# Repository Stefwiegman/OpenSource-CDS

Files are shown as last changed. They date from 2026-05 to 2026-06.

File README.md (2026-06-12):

# Confocal Displacement Sensing

> **Affordable confocal displacement measurement.**
> *Confocal Displacements Sensing voor betaalbare verplaatsingsmetingen*

<p align="center">
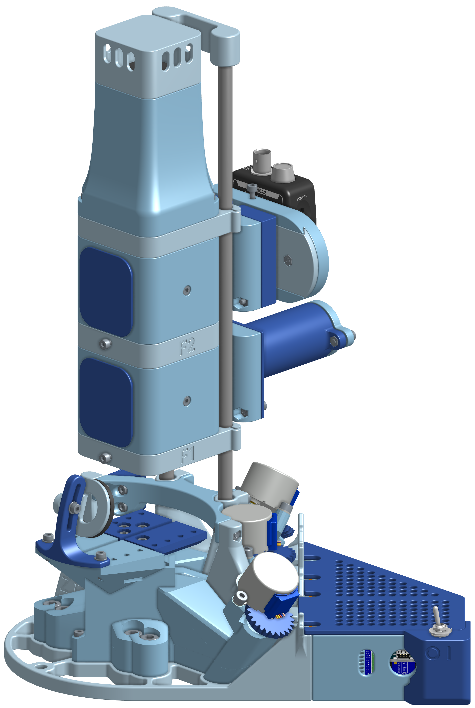
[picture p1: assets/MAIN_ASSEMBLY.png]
Confocal Displacement Sensor, CAD render of the assembled instrument
  
</p>

    

A Bachelor End Project (BEP) for the **Precision and Micro-Engineering** track at TU Delft (course `WBMT3BEP`, project code `PME-2026-A06`).
Submission: **June 12th 2026**.

**Team:** Dafne Gyselinck · Jayden Jhagru · Harmen Klerk · Ties van Lohuizen · Stef Wiegman

> 🧱 **Built on top of the [OpenFlexure Block Stage](https://openflexure.org/projects/blockstage/)** (CC BY-SA 4.0), used **unmodified** as our 3-axis flexure base. See [Built on top of](#-built-on-top-of) for what this means for builders, and for attribution.

---

## 🔗 Project Hub

Everything we made for this project lives behind one of these links.

| Deliverable | Link | What's inside |
|---|---|---|
| 📄 Research paper | [`docs/OpenSource_CDS_Paper.pdf`](docs/OpenSource_CDS_Paper.pdf) | "Frugal & Portable Monochromatic Confocal Displacement Sensing using the OpenFlexure framework": theory and confocal intensity model (Section II), grid-search lens selection, measured sensitivity vs. range, AFM-cantilever alignment, frequency-domain demonstration, discussion (PDF, download to view) |
| 🎥 Assembly video | [YouTube](https://youtu.be/qtCvRlFayCg) | Step-by-step build from printed parts and electronics to a working instrument |
| 📐 CAD files | [`cad/`](cad/) | 51 STEP files (`cad/step/`) for the confocal extension, plus 6 STL of the OpenFlexure stage (`cad/stl/`), grouped by category (BASE / BLOCKS / CALIBRATION / STAGE) |
| 🧩 Assembly viewer | [Onshape](https://cad.onshape.com/documents/87fafcc64806dd978cd8e8a6/w/b53780b5a9e32836df5ce22e/e/844e572a161a9db474edfe58) | Interactive 3D model of the full assembly: rotate and inspect in the browser, or export STEP / STL yourself |
| 🔧 Circuit diagram | [`docs/circuit-diagram.pdf`](docs/circuit-diagram.pdf) | Arduino pin-out, ULN2003 IN2/IN3-swap, power, Moku and camera connections (PDF, download to view) |
| 🛒 Parts list (BOM) | [`docs/OpenSource_CDS_BOM.xlsx`](docs/OpenSource_CDS_BOM.xlsx) | Electronics, optics, mechanical hardware, quantities, suppliers, prices (Excel, download to view) |
| 🖨️ 3D-print guide | [`docs/OpenSource_CDS_Printing_Guide.pdf`](docs/OpenSource_CDS_Printing_Guide.pdf) | Printer settings, per-part list with print times, filament estimates, tolerances |
| 📖 Use guide | [`docs/OpenSource_CDS_User_Guide.pdf`](docs/OpenSource_CDS_User_Guide.pdf) | Optical alignment (tower, LED, mirror, detector), laser calibration, powering on, homing the stage, finding I0 and the calibration sweep (PDF, download to view) |
| 🧱 Block stage origin | [openflexure.org/projects/blockstage](https://openflexure.org/projects/blockstage/) | Upstream open-hardware base, required reading before fabrication |
| 💻 Source code | this repository | PySide6 desktop UI, Arduino firmware, burst pipeline, confocal physics model |

---

## What is this?

A complete, low-cost **confocal displacement measurement instrument**, built from four parts:

- An **unmodified [OpenFlexure Block Stage](https://openflexure.org/projects/blockstage/)** as the 3-axis flexure base
- Our custom **confocal optical column** (two lenses, pinhole aperture, photodetector) that bolts onto the block stage
- Our **stepper actuators, electronics, and illumination** that also mount to the unmodified stage
- A desktop application that ties it all together for live alignment, calibration, and manual point measurements

The instrument **measures sub-micron axial displacement** (vertical position changes smaller than 1 µm) at one point on a sample. Repositioning the probe across a grid builds a spatial map: at each stand-still point the photodetector records a high-speed voltage burst (a few milliseconds at ≥1 MSa/s), and offline FFT analysis turns each burst into a vibration spectrum.

The goal is to deliver this capability at a small fraction of the cost of commercial confocal displacement sensors, making the technology accessible for academic and small-lab settings.

The motivating application is **vibration characterisation of MEMS-class structures**: each burst's spectrum becomes one point in a 3D dataset `(x, y, frequency) → amplitude`. In the paper this is demonstrated by aligning the laser on an AFM cantilever (≈450 µm × 50 µm) and recovering the known vibration frequencies of a stepper motor.

### Glossary

If terms below are new to you, this short table covers the rest of the README:

| Term | What it means here |
|---|---|
| **Confocal** | Optical setup where the illumination spot and detector pinhole share a common focus, gives the system its high axial (Z-axis) sensitivity |
| **Burst** | A short (few ms) high-rate sample of photodetector voltage taken at one stand-still position |
| **dz1** | Axial (Z) displacement of the sample from a reference plane, in mm |
| **I0** | Photodetector voltage at full reflection (the maximum of the calibration curve); the linear region sits around I0/2 |
| **Calibration line** | A straight line `I_m = a·dz1 + b` fitted to the steep middle of the confocal curve; inverting it (`dz1 = (V - b) / a`) turns measured voltage into displacement |
| **MEMS** | Micro-Electro-Mechanical Systems, micrometer-scale moving structures whose vibrations we characterise |
| **Moku:Go** | Liquid Instruments' multifunction lab instrument; it is the acquisition **back-end** that digitises the photodetector signal (Oscilloscope mode for live view, Datalogger mode for burst capture) |
| **Flexure stage** | A stage that moves via elastic flexion of monolithic features instead of sliding bearings, sub-micron repeatable, see OpenFlexure |

### Pick your starting point

- **Reading the paper?** Start with the [research paper](#-project-hub), then the [Hardware overview](#hardware-overview) for the optical setup.
- **Building a copy?** Read [Built on top of](#-built-on-top-of) first, then open the [3D-print guide](docs/OpenSource_CDS_Printing_Guide.pdf), [BOM](docs/OpenSource_CDS_BOM.xlsx), [circuit diagram](docs/circuit-diagram.pdf), and watch the [assembly video](https://www.youtube.com/watch?v=UzMbLptgHZc).
- **Running an existing instrument?** Jump to [Prerequisites](#prerequisites) and [Setup](#setup), then the [use guide](docs/OpenSource_CDS_User_Guide.pdf).
- **Hacking the software?** See [Repository layout](#repository-layout).

---

## Prerequisites

Before the software will do anything useful, make sure you have:

| Need | Why | How to verify |
|---|---|---|
| **Python ≥ 3.10** | UI + burst pipeline | `python --version` |
| **Git** | clone repo | `git --version` |
| **Arduino IDE** (or `arduino-cli`) | flash the Nano firmware once | open IDE, plug in Nano |
| **Moku:Go** + Liquid Instruments account | photodetector readout | reachable at `192.168.73.1` after connecting to its Access-Point Wi-Fi or Ethernet |
| **USB microscope camera** (UVC, ≥1080p) | live view of the sample on the Camera tab | the laptop's built-in webcam is never used; only an external camera is opened |
| **Assembled hardware** | otherwise the UI starts but cannot measure | see [3D-print guide](docs/OpenSource_CDS_Printing_Guide.pdf), [circuit diagram](docs/circuit-diagram.pdf), and the [assembly video](https://www.youtube.com/watch?v=UzMbLptgHZc) |

Estimated total build cost: **≈ €1600**, dominated by the Moku:Go (≈ €689) and the optics (lens and red filter, listed as approximate prices); see the [BOM](docs/OpenSource_CDS_BOM.xlsx) for the full breakdown.

---

## Setup

This chapter takes you from a fresh clone to all three TopBar status pills (`Motors / Moku / Camera`) turning green. For aligning and calibrating the instrument afterwards (optical alignment, laser calibration, finding I0, calibration sweep) see the [use guide](docs/OpenSource_CDS_User_Guide.pdf).

### 1. Clone and create a Python environment

**Windows (PowerShell):**

```powershell
git clone https://github.com/Stefwiegman/Bep-Project.git
cd Bep-Project
python -m venv .venv
.venv\Scripts\Activate.ps1
```

**Linux / macOS (bash/zsh):**

```bash
git clone https://github.com/Stefwiegman/Bep-Project.git
cd Bep-Project
python3 -m venv .venv
source .venv/bin/activate
```

### 2. Install dependencies

```bash
pip install -r requirements.txt
```

This pulls in the UI and pipeline stack: PySide6 (Qt UI), pyserial (Arduino link), the `moku` client, NumPy + matplotlib (math and plots), SymPy (confocal model), OpenCV + pygrabber (camera), pandas + openpyxl (Excel/CSV import in the Calibration graph tab) and PyYAML (calibration persistence).

> **Note:** `openpyxl` is the engine pandas uses to read `.xlsx` files. Without it the Calibration graph tab cannot open Excel measurement files, so it is pinned in `requirements.txt` even though pandas does not install it automatically.

### 3. Flash the Arduino firmware (one-time)

The stage motors and lamp are driven by an Arduino Nano. Flash it once with the Arduino IDE (or `arduino-cli`):

1. Open `arduino/firmware/firmware.ino`.
2. Install the required libraries via the Library Manager: **AccelStepper** and **Adafruit NeoPixel**.
3. Select board **Arduino Nano** and the correct COM-port, then **Upload**.

Note the port the Nano enumerates on, you pick it in the app later (the defaults assume `COM4`). Full wiring, including the ULN2003 IN2/IN3 swap, is in the [circuit diagram](docs/circuit-diagram.pdf).

### 4. Set up the Moku:Go (one-time)

The `moku` Python client deploys an instrument bitstream (Oscilloscope / Datalogger) to the Moku:Go's FPGA at runtime, and that bitstream must match the device's MokuOS version. Install the Liquid Instruments CLI, point the Python client at it, and cache the matching bitstreams once:

1. **Install the CLI.** Download and install `mokucli` from Liquid Instruments: [liquidinstruments.com/software/utilities](https://liquidinstruments.com/software/utilities/). On Windows it lands at `C:\Program Files\Liquid Instruments\Moku CLI\mokucli.exe`. **Keep the default install folder.** The Python client locates `mokucli` through the path you set in the next step, so moving the install folder breaks bitstream deployment.

2. **Tell the `moku` client where the CLI is.** Set the `MOKU_CLI_PATH` environment variable to the executable from the previous step. On Windows (run once, in a normal PowerShell or Command Prompt, then open a new terminal so the variable is picked up):
   ```powershell
   setx MOKU_CLI_PATH "C:\Program Files\Liquid Instruments\Moku CLI\mokucli.exe"
   ```
   If you installed `mokucli` somewhere else, point this at that path instead.

3. **Find the device security key.** Each Moku:Go has a unique key printed on the **sticker on the bottom of the device**. You need it the first time you claim or connect to the Moku:Go through your Liquid Instruments account.

4. **Read the MokuOS version.** Connect to the device first: join the Moku:Go's Wi-Fi Access Point or wire it over Ethernet, put your PC's network adapter on the same subnet (`192.168.73.x`), confirm it responds, then list it and note the firmware version reported:
   ```bash
   ping 192.168.73.1
   mokucli list
   ```

5. **Download the matching bitstreams.** This step pulls the bitstreams from Liquid Instruments' servers, so you must be **connected to the internet** (switch off the Moku:Go Access-Point Wi-Fi and back onto your normal network first). Use the version from the previous step and the `mokugo` hardware flag:
   ```bash
   mokucli instrument download <mokuos_version> --hw-version mokugo
   ```
   For example, for MokuOS 4.2.1: `mokucli instrument download 4.2.1 --hw-version mokugo`.

Stuck on any of these? Liquid Instruments' AI support assistant covers CLI install and firmware issues: [liquidinstruments.com/support](https://liquidinstruments.com/support/).

### 5. Connect the microscope camera

Plug in the external USB microscope camera (UVC, ≥1080p). The laptop's built-in webcam (index 0) is never opened, so it stays off until a microscope camera is connected on index 1+.

### 6. Launch and connect

```bash
python ui.py
```

In the app, open the **Setup tab**, pick your Arduino COM-port and click **Connect**. The TopBar pills `Motors / Moku / Camera` should all turn green. If one stays red, recheck the cabling and power for that subsystem; the [use guide](docs/OpenSource_CDS_User_Guide.pdf) walks through the full power-on sequence.

> **Windows Firewall (first launch).** The first time the app opens a network socket, Windows shows a firewall prompt. Allow access on **Private networks** so the app can reach the Moku:Go. If you dismissed it or ticked the wrong box, the Moku pill stays red: open **Windows Security → Firewall & network protection → Allow an app through firewall**, find Python (or the app), and enable its **Private** checkbox.

> **Display scaling.** The window sizes itself to fit the screen it opens on, so it stays usable on smaller or DPI-scaled laptops (Windows display scaling of 125% / 150% is handled). On a display too small for the full layout it opens maximized; drag the splitter bars to rebalance the camera, sidebar, and Moku plot.

**Defaults:** Arduino on `COM4 @ 9600 baud`, Moku at `192.168.73.1` (50 Vpp range), external microscope camera auto-detected (MJPG @ 1080p/30 fps). The laptop's built-in webcam (index 0) is never opened.

With all pills green, continue in the [use guide](docs/OpenSource_CDS_User_Guide.pdf) to align the optics, find the I0 reference, and run the calibration sweep. Recording measurements afterwards is done in the app (see [UI layout](#ui-layout) and [How it works](#how-it-works)).

---

## Hardware overview

| Subsystem | Details |
|---|---|
| **Stage** | **Unmodified [OpenFlexure Block Stage](https://openflexure.org/projects/blockstage/)** as the flexure base, with our 3× 28BYJ-48 stepper + ULN2003 driver actuators bolted on. Driven by an Arduino Nano (`COM4`, 9600 baud). Motor 1 = X, motor 2 = Y, motor 3 = Z (focus). |
| **Optical column** | Two-lens confocal path: interchangeable F1 lens (16-80 mm, code default 40 mm) with a fixed `f2 = 150 mm`, detector aperture (`r_d = 0.5 mm`), mounted vertically above the stage. Full derivation in the [research paper](#-project-hub), implementation in [`confocal.py`](confocal.py). |
| **Lamp** | Two WS2812B-8 LED rings (inner on Arduino pin A2, outer on pin A3), brightness controlled over the shared serial port |
| **Photodetector** | Moku:Go (Oscilloscope mode for live view, Datalogger mode for burst capture), IP `192.168.73.1`, 50 Vpp range |
| **Camera** | External USB microscope camera, auto-detected on indices 1+, MJPG @ 1080p / 30 fps. The laptop's built-in webcam (index 0) is never opened, so it stays off until a microscope camera is connected. |

Full pin-out, schematic and connector list → [`docs/circuit-diagram.pdf`](docs/circuit-diagram.pdf). Parts and suppliers → [`docs/OpenSource_CDS_BOM.xlsx`](docs/OpenSource_CDS_BOM.xlsx). 3D-print files and settings → [`docs/OpenSource_CDS_Printing_Guide.pdf`](docs/OpenSource_CDS_Printing_Guide.pdf).

---

## UI layout

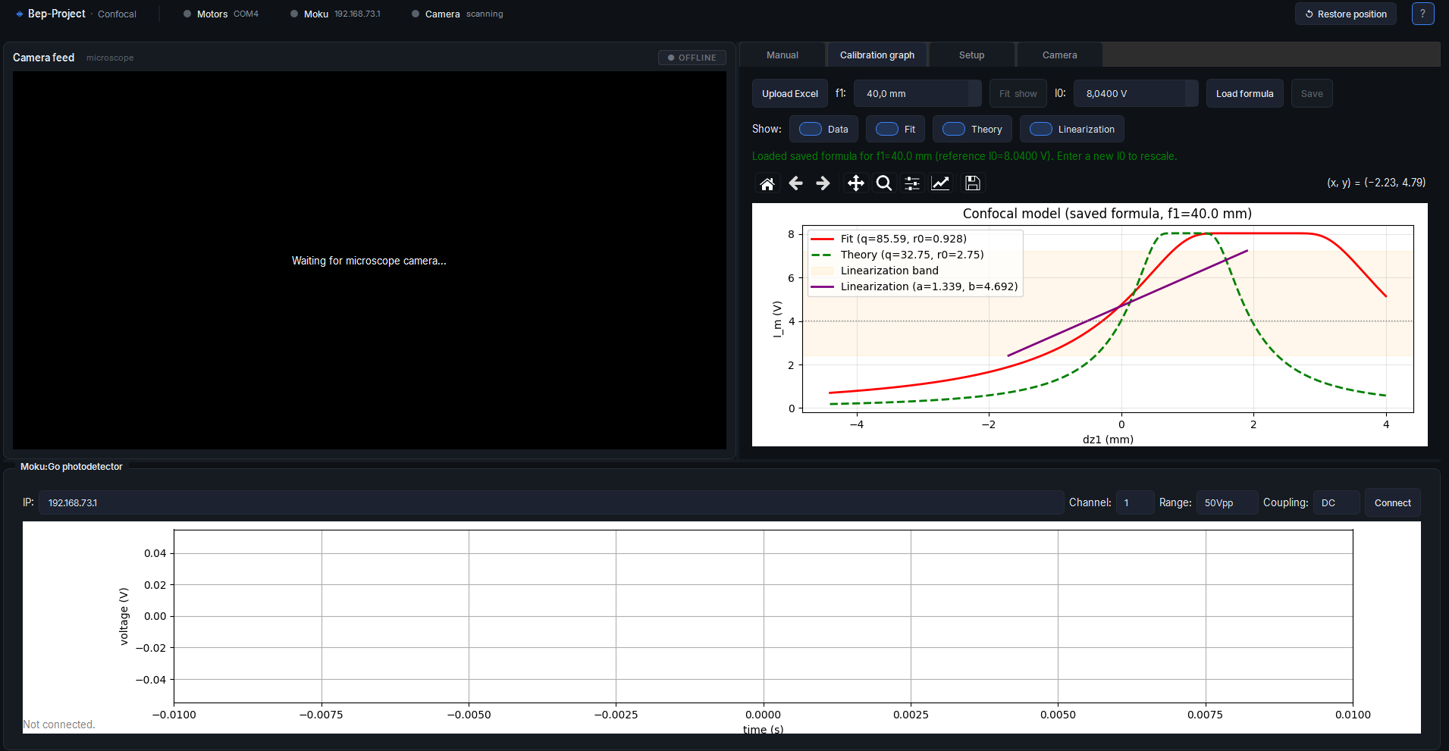
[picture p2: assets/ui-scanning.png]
Confocal Displacement Sensor UI: TopBar status pills, camera feed (OFFLINE until connected), the Calibration graph tab with the fitted confocal model, and the live Moku:Go photodetector plot


| Tab | What it does |
|---|---|
| **Manual** | One burst at the current motor position. Converts voltage to displacement with the linearized calibration line (`dz1 = (V - b) / a`) and warns if the signal leaves the linear band. Output: `data/manual_<ts>_<name>/` with `burst.csv` (raw voltage), `position.csv` (dz1), `fft.png`, and `metadata.txt`. |
| **Calibration graph** | Upload measurement points (dz1, I_m) as Excel/CSV, fit the confocal A6 model and linearize around I0/2. The fitted line is the source of truth the Manual tab uses for the voltage to displacement conversion. |
| **Setup** | Connect, jog in exact micron steps, soft-home ("Set 0 here"), set speed, restore the last saved position. |
| **Camera** | Exposure, brightness, contrast, auto-exposure, grayscale, plus the inner and outer lamp brightness controls. |

Step-by-step optical alignment and calibration → [`docs/OpenSource_CDS_User_Guide.pdf`](docs/OpenSource_CDS_User_Guide.pdf).

---

## How it works

The voltage to displacement conversion is built in two steps.

1. **Calibrate (once per setup).** In the **Calibration graph** tab you upload measured `(dz1, I_m)` points. The confocal A6 model is fitted to them, and the steep middle of the curve (around I0/2) is linearized into a straight line `I_m = a·dz1 + b`. That line, with its valid voltage band `[lo, hi]`, is what every later measurement uses.

2. **Measure (per point).** In the **Manual** tab the stage settles to a halt, the Moku:Go records a high-sample-rate voltage burst from the photodetector, and the burst is saved as raw CSV. Each sample is converted to an axial displacement with the inverted line `dz1 = (V - b) / a`. If part of the burst leaves the linear band, the UI raises a warning, because the displacement there would be an extrapolation. Each burst is FFT-analysed to show the vibration spectrum at that point.

Repeating step 2 across a grid of positions (repositioned with the Setup tab jog controls) builds the 3D dataset `(x, y, frequency) → amplitude`.

Full theoretical background and derivations: see the [research paper](#-project-hub).

---

## Repository layout

| File | Role |
|---|---|
| `ui.py` | Main window, CameraThread (microscope-camera auto-detect), MotorPanel, MokuPanel, TopBar, layout |
| `recording.py` | Manual burst (one click = one measurement), voltage to dz1 via the calibration line, FFT popup |
| `calibration_graph.py` | Calibration graph tab: upload points, fit the A6 model + linearization, plot, save results |
| `ml.py` | Confocal A6 model fit (learns q, r0) and the linearization around I0/2 |
| `lamp.py` | WS2812B brightness via slider, throttled @ 20 updates/s (inner + outer rings) |
| `camera_settings.py` | Exposure / brightness / contrast / auto-exposure / grayscale (Camera tab) |
| `datalogger.py` | Moku Datalogger wrapper, streaming burst acquisition (raw voltage) |
| `calibration.py` | Persistence of mm/step + last position → `calibration.yaml` |
| `confocal.py` | Physics core: formula A6, `compute_q` / `Im` / `dz1` / `Sm` (sympy + numpy) |
| `gridsearch.py` | Sweep over f1/f2 → measurement-range analysis → CSV (standalone) |
| `viewer.py` | 3D plot + heatmap of scan data (standalone CLI) |
| `styles.qss` | Qt stylesheet (design tokens) |
| `arduino/firmware/firmware.ino` | Nano firmware: AccelStepper + NeoPixel, ASCII command protocol |

---

## 🧱 Built on top of

This instrument uses the open-hardware **[OpenFlexure Block Stage](https://openflexure.org/projects/blockstage/)** ([GitLab source](https://gitlab.com/openflexure/openflexure-block-stage)) by the OpenFlexure project as its 3-axis flexure base. We use the block stage **completely unmodified**: our confocal optical column, stepper actuators, electronics housing, and illumination are designed as a **bolt-on extension** that mounts to the standard block stage without any changes to its parts.

Two practical consequences:

- **If you already own an OpenFlexure Block Stage**, you only need to print our confocal-extension parts ([`cad/step/`](cad/step/)) and bolt them on. **If you don't**, the stage is bundled as STL in [`cad/stl/`](cad/stl/) so you can print a complete instrument from this repo. Either way the stage is used without modification.
- **The extension is reversible**: unbolt our parts and the block stage returns to its original state and original use cases (microscopy, etc.).

Every part of our confocal setup is deliberately designed to be straightforward to modify for users with non-standard requirements (different optics, sample sizes, illumination, mounting).

| Aspect | Source |
|---|---|
| 3-axis flexure stage | **OpenFlexure Block Stage** (used unmodified) |
| Stepper actuators + electronics | Our own design (mounts to the unmodified stage) |
| Confocal optical column (f1, f2, aperture, photodetector) | Our own design |
| Software (UI, firmware, analysis, paper) | Our own work |

**Licensing.** The OpenFlexure Block Stage is licensed under **CC BY-SA 4.0** (Attribution + ShareAlike). Because we use it unmodified, our extension parts are technically not a "derivative" of the stage's CAD. We still release our extension under **CC BY-SA 4.0** to keep the open-hardware chain intact and to match the upstream licence. The stage STL bundled in [`cad/stl/`](cad/stl/) are the upstream OpenFlexure parts, redistributed unmodified under that same CC BY-SA 4.0 licence. Our software is independent and uses the permissive MIT licence (see [License](#license)).

**Attribution.** When using or referencing this project's hardware:

> *Confocal extension for the [OpenFlexure Block Stage](https://openflexure.org/projects/blockstage/) by the OpenFlexure project, © OpenFlexure, CC BY-SA 4.0.*

---

## Credits

Bachelor End Project for the *Precision and Micro-Engineering* track, **TU Delft**, academic year 2025–2026.
Course `WBMT3BEP`, project code `PME-2026-A06`.

**Team:** Dafne Gyselinck · Jayden Jhagru · Harmen Klerk · Ties van Lohuizen · Stef Wiegman.

**Supervisors:** Ruben Guis & Gerard Verbiest.

Hardware base: **OpenFlexure Block Stage** by the OpenFlexure project (CC BY-SA 4.0).

---

## License

This project combines our own software with hardware derived from an open-hardware base, so it uses **two licences**:

| Part | Licence | File |
|---|---|---|
| **Software** (Python, Arduino firmware, Qt stylesheets) | **MIT** | [`LICENSE`](LICENSE) |
| **Hardware / CAD** (3D-print files, STEP/STL release) | **CC BY-SA 4.0** | [`LICENSE.hardware`](LICENSE.hardware) |
| **Documentation** (this README, `docs/`, research paper) | **CC BY-SA 4.0** | [`LICENSE.hardware`](LICENSE.hardware) |

The hardware and documentation use CC BY-SA 4.0 to match the upstream [OpenFlexure Block Stage](#-built-on-top-of); the software is independent and uses the permissive MIT licence. See [Built on top of](#-built-on-top-of) for the rationale.

Copyright held jointly by the BEP team (Dafne Gyselinck, Jayden Jhagru, Harmen Klerk, Ties van Lohuizen, Stef Wiegman), 2026.

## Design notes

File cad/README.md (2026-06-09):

# CAD files

Print files for the confocal displacement sensor: our confocal extension (STEP source) plus the OpenFlexure Block Stage it mounts to (STL).

## What's here

| Folder | Contents |
|---|---|
| `step/` | 51 STEP source files for every part of our confocal extension. Open directly in your slicer (Cura, PrusaSlicer, OrcaSlicer) to print, or import in a CAD package (FreeCAD, SolidWorks, Onshape, Fusion 360) to modify. |
| `stl/` | 6 STL meshes of the OpenFlexure Block Stage (the 3-axis flexure base), redistributed unmodified so you can print a complete instrument from one place. Slice and print as-is. |

## Part naming

Files are grouped by category prefix:

| Prefix | Category | Examples |
|---|---|---|
| `BASE_*` | Base and structural parts | `BASE_base.step`, `BASE_bridge.step`, `BASE_electro.step` |
| `BLOCKS_*` | Modular optical blocks (camera, detector, lens, mirror, laser, spacers, red filter) | `BLOCKS_f1_block.step`, `BLOCKS_detector_block.step`, `BLOCKS_spacer_0.4.step` |
| `CALIBRATION_*` | Calibration jigs, spacers and tools | `CALIBRATION_spacer_0.4.step`, `CALIBRATION_table_calibrator.step` |
| `STAGE_*` | OpenFlexure Block Stage parts, in `stl/` | `STAGE_main_body.stl`, `STAGE_gears.stl`, `STAGE_moving_platform.stl` |

## The block stage

The `stl/` folder holds the **[OpenFlexure Block Stage](https://gitlab.com/openflexure/openflexure-block-stage)** parts, redistributed **unmodified** under CC BY-SA 4.0. If you already own a printed and assembled block stage, skip the `STAGE_*` STL and print only the `step/` extension parts. For the latest stage sources, parameters and updates, use the upstream OpenFlexure repo.

## How to print

1. Open the relevant `.step` (extension) or `.stl` (stage) file in your slicer (Cura, PrusaSlicer, OrcaSlicer)
2. Apply the recommended settings from [`../docs/OpenSource_CDS_Printing_Guide.pdf`](../docs/OpenSource_CDS_Printing_Guide.pdf)
3. Print, post-process, and assemble per the [assembly video](https://www.youtube.com/watch?v=UzMbLptgHZc)

## How to modify

Open a `.step` file in any parametric CAD package (FreeCAD is free and open-source; SolidWorks, Onshape, Fusion 360 also work). The feature tree is preserved so you can adjust dimensions, mounting points, etc. to fit your own setup. The `STAGE_*` parts are provided as STL meshes only; modify those via the upstream OpenFlexure sources.

## Licence

CC BY-SA 4.0. See [`../LICENSE.hardware`](../LICENSE.hardware) for the full text and the rationale for matching the upstream OpenFlexure licence.

When forking or remixing, please credit:

> *Confocal extension for the [OpenFlexure Block Stage](https://openflexure.org/projects/blockstage/) by the OpenFlexure project, (c) OpenFlexure, CC BY-SA 4.0.*

The bundled `stl/STAGE_*` parts are the OpenFlexure Block Stage by the OpenFlexure project (CC BY-SA 4.0), redistributed unmodified.

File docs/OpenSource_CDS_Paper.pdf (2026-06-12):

## OpenSource CDS | Frugal & Portable Monochromatic Confocal Displacement Sensing using the OpenFlexure framework

BEP PME-A06 | D. Gyselinck, J. Jhagru, H. Klerk, T. van Lohuizen & S. Wiegman

Abstract—Characterising micro-scale displacement and vibration is important in precision engineering and micro-system diagnostics, but conventional measurement systems such as Laser Doppler Vibrometers are often too expensive for low-budget research and educational environments. This paper presents the development of a portable and cost-efficient Confocal Displacement Sensing (CDS) setup based on the OpenFlexure framework. The system combines a custom confocal optical tower with an OpenFlexure Block Stage and a software-controlled measurement pipeline. Experimental measurements confirmed that axial displacement can be measured through changes in detector voltage. By varying the objective focal length between 16 mm and 80 mm, the measured sensitivity varied from 7,529 V /mm to 0,601 V /mm, while the linear range increased from 0,638 mm to 7,989 mm. The setup was also aligned with an AFM cantilever and used for frequency-domain measurements. These results demonstrate the working principle of a low-cost CDS system for tunable displacement and vibration measurements.

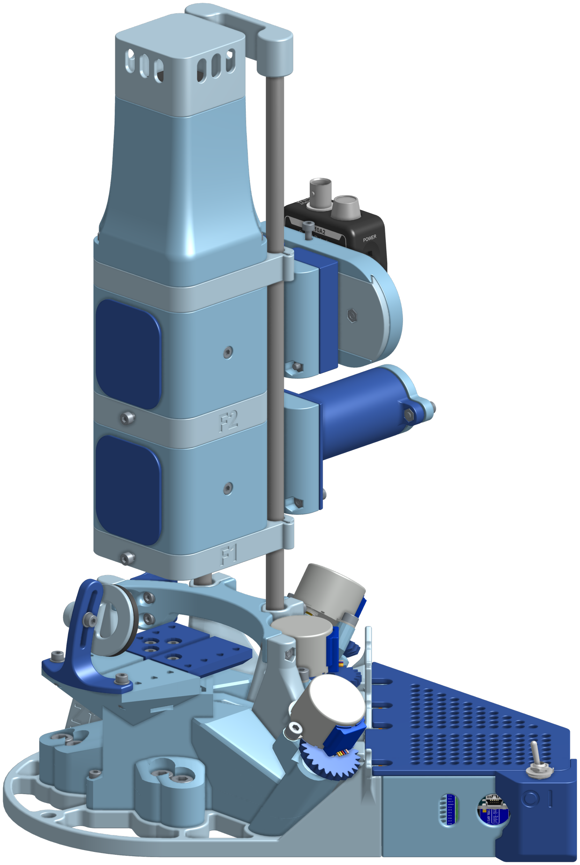
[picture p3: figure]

Fig. 1. The full assembly of the OpenSource CDS

I. INTRODUCTION
In precision engineering and micro-system diagnostics, characterising the dynamic behaviour of micro-scale moving structures is essential for evaluating structural oscillations and elastic deformations. This is especially relevant for micro-electromechanical systems (MEMS), where small micro-scale displacements and vibrations, both in-plane and out-of-plane, can strongly influence device performance [1]. Contactless optical measurement methods are well suited for these applications, because they allow displacement and vibration measurements without mechanically loading the sample. Using optics also allows for a high bandwidth of different methods that can be used for measuring.

Conventional industrial measurement instruments, such as Laser Doppler Vibrometers (LDVs), can provide high-precision vibration measurements, but they are often financially inaccessible for low-budget research environments

[1]. This accessibility gap motivates the development of low-cost measurement systems that can demonstrate similar measurement principles, even if they do not reach the full performance of commercial instruments [2]. Besides, using the constructed setup (Fig. 1) portability could also be greatly increased compared to conventional LDVs.

This paper investigates the viability of an affordable and flexible alternative to LDVs, based on monochromatic confocal displacement sensing [3]. In a confocal displacement sensor, the measured detector intensity changes with the axial position of the sample. This makes the principle suitable for contactless displacement measurement. The system developed in this project extends the unmodified 3D-printed OpenFlexure Block Stage [4] with a custom confocal optical tower and a software-controlled measurement pipeline.

The research question of this work is:
To what extent is it possible to measure displacements and vibrations over a tunable range using a cost-efficient confocal displacement sensing setup with sufficient accuracy for micro-engineering applications?

II. THEORY

The confocal optical tower is realised through the use of a photodetector combined with two convex lenses through which a laser beam passes. In a confocal system, the illumination path and the detection path are focused on the same point [5],[6]. When the sample is in focus, the light returning to the detector is concentrated near the detector aperture, so a large fraction of the light is measured. When the sample moves axially away from focus, the beam between the lenses loses parallelity, and therefore, the effective spot at the detector becomes larger. As a result, less light passes through the aperture and the measured detector voltage decreases (see Fig. 2B).

The detector response (Im) is described by the following intensity model [3], with I0 being the maximum intensity measured with the detector in focus:

Im = I0 − I0 exp
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
where rd is equal to the detector aperture radius and rdet is given by the following equation:

rdet =

r0

−2Ldz1q + 2dz1f1q + 2dz1f

2
2 + 2dz1f2q − f
2/1 q
f

2/1 f2
(2)
All variables are defined by the schematic given in Fig. 2B.

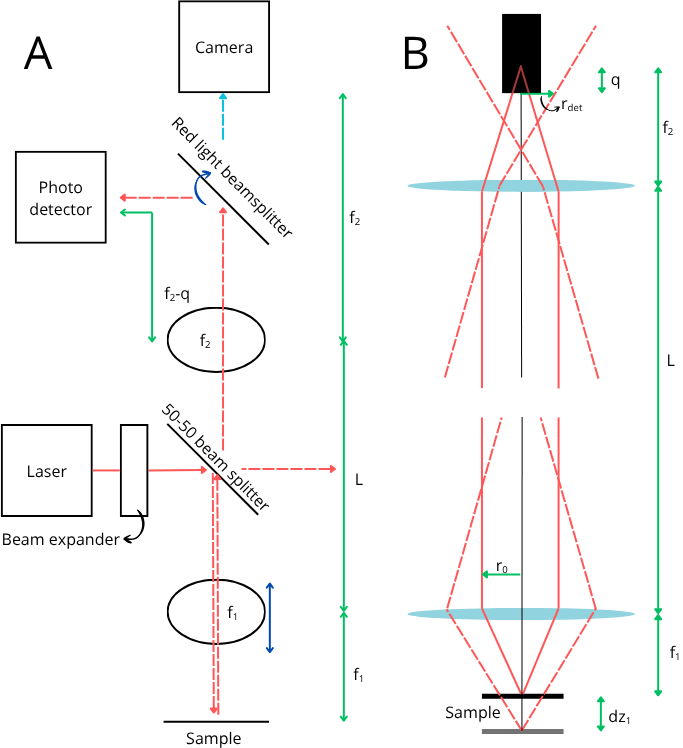
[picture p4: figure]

Fig. 2. A: The confocal setup used inside of the OpenSource CDS
B: Visualization of the working principle of confocal displacement sensing

The model predicts that the detector voltage changes with axial displacement. Around the steep part of the focus curve, a small change in axial position produces a relatively large change in measured voltage. This region is therefore important for displacement sensing. To reach this steep part of the curve with the sample in focus, a detector offset q is introduced, which is described by the following equation:

q =

f2rd
r0

p
ln(2)

(3)

Equations 1 and 2 also show a trade-off between sensitivity and measurement range. A shorter objective lens focal length (f1) is expected to give a higher sensitivity but a smaller usable range, while a longer focal length gives a larger range but lower sensitivity.

III. METHODS

The confocal sensing tower is designed using commercially available and 3D-printed parts (with an estimated price of C1600,-) to guide both the illumination light and the reflected measurement signal through the same compact optical structure, which is schematically visualized in Fig. 2A. The light path starts at the monochromatic laser source, which emits a narrow beam (of 650 nm) into the tower. This beam first passes through a beam expander to increase the beam diameter. After expansion, the beam passes through a pinhole (with radius r0 = 2,75 mm), which creates a cleaner circular illumination beam.

The beam is then directed towards a beam splitter. This beam splitter acts as a partially transmitting mirror; part of the incoming light is redirected into the vertical optical path, while the rest is lost. The reflected part of the laser beam travels downwards through the objective lens (f1), which focuses the light onto the sample surface. By varying the objective, different ranges and sensitivities can be explored.

After interacting with the sample, the reflected light travels back upwards through the same lens. The beam then passes through the beam splitter, again losing half of its intensity. The remaining signal continues through the second lens (f2), with a fixed focal length. This lens forms the detection path and determines the effective spot size at the detector side of the system.

Behind lens f2, the returning light reaches a short-pass filter that separates the red laser-beam towards the detector (with aperture radius rd = 0,5 mm) from the imaging path towards the camera. The camera is used mainly for visual alignment of the sample and optical path, while the photodetector signal is used for the actual displacement measurement.

Through the use of a grid-search, all pairs of f1 and f2 values have been analysed. Using the results of this grid-search, the optimal f2 could be chosen along with different objective focal lengths to achieve the desired range.

TABLE I
RESULTS OF THE GRIDSEARCH ON THE DIFFERENT f1 AND f2 PAIRS
f1 (mm) | f2 (mm) | q (mm) | Sensitivity (mm⁻¹
) | Range (mm)
16 | 150 | 32,758 | 4,261 | 0,328
25 | 150 | 32,758 | 3,476 | 0,792
40 | 150 | 32,758 | 2,593 | 1,989
60 | 150 | 32,758 | 2,092 | 4,368
80 | 150 | 32,758 | 1,267 | 7,583

The setup is controlled with custom Python software. The software provides a single interface for controlling the stage movement, monitoring the detector output and starting measurements.

Before measurements are performed, an optical alignment procedure is mandatory. The procedure consists of a one-time alignment of the optical tower and a repeated alignment for each sample. During the one-time alignment, the laser and beam splitter are adjusted until the laser-beam is parallel and in line with the tower, after which the short-pass filter is tuned until the signal is maximised. The detector is then translated laterally to maximise its signal and centre the focused reflected beam on the detector aperture.

Then, the sample is manually positioned on the stage, after which the stage actuators (in X,Y and Z direction) are used for finer alignment and find the maximum detector signal. From this maximum signal position, the tower is moved upward until the detector signal decreases to approximately half of its maximum, which positions the signal on the steepest part of the slope. Finally, the Zaxis of the stage is used again to fine-tune the signal at this half-maximum operating point before starting the measurement.

| | IV. RESULTS

The optical setup is first evaluated by positioning the laser beam on a micro-scale sample. The combination of lenses allows for a microscopic view of the sample through the camera. This makes it possible to visually align the laser spot with the sample. Fig. 3 shows the laser positioned on an AFM cantilever sample with approximate dimensions of 450 µm by 50 µm. Using the X and Y actuators of the OpenFlexure stage, the laser spot can be located on different spots on the cantilever.

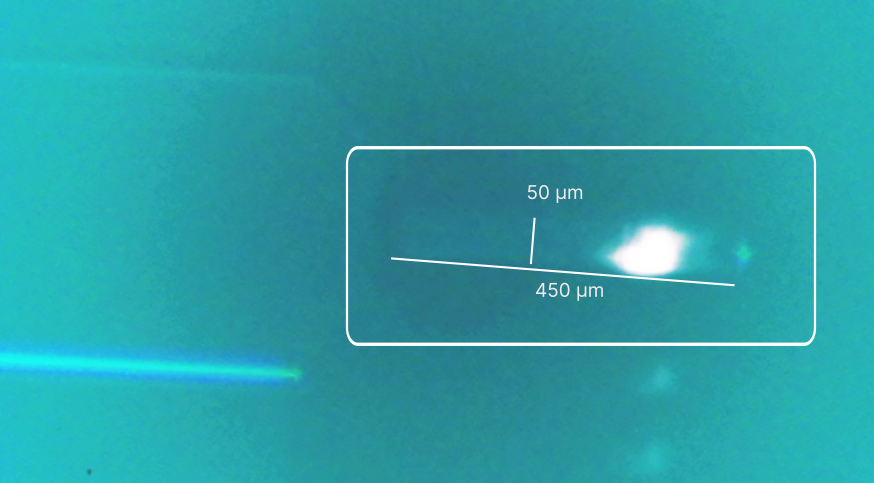
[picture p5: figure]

Fig. 3. Camera image of the laser spot positioned on an AFM cantilever (f1 = 16 mm, magnification of ×9, 4)

To characterise the axial response of the confocal system, intensity curves are obtained for different values of f1. For each lens configuration, spacers with 0, 2 ± 0, 05 mm thickness are used to create a sweep of axial positions. At each position, the detector voltage is recorded. This produces a relation between axial displacement and measured intensity. The measured data-points are then fitted using the theoretical confocal response described in section II.

Fig. 4 shows the measured system follows the same general trend as the theoretical model; however, the theoretical graph did not fully match the physical implementation. The fitted curve required different effective parameters (r0 and q) than the theoretical model.

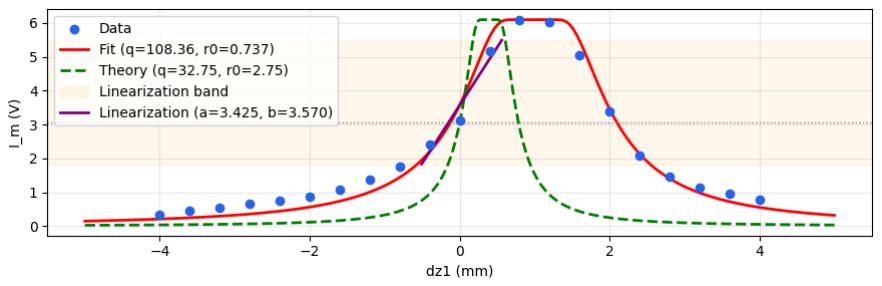
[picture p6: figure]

Fig. 4. Visualisation of the fitted curve versus the theoretical model, including the linearization

To simplify displacement measurements, the steep part of the curve is linearized without loss of significant precision. The linearization band is visually determined to be [I0/2−0, 2I0, I0/2 + 0, 4I0].

Fig. 5 shows the fitted curves for focal lengths between 16 mm and 80 mm, with the peaks aligned at zero for comparison. The curves show that changing f1 strongly affects both the width and the slope of the response. Shorter focal lengths produce a narrower and steeper response, while longer focal lengths produce a wider response with a larger usable displacement range.

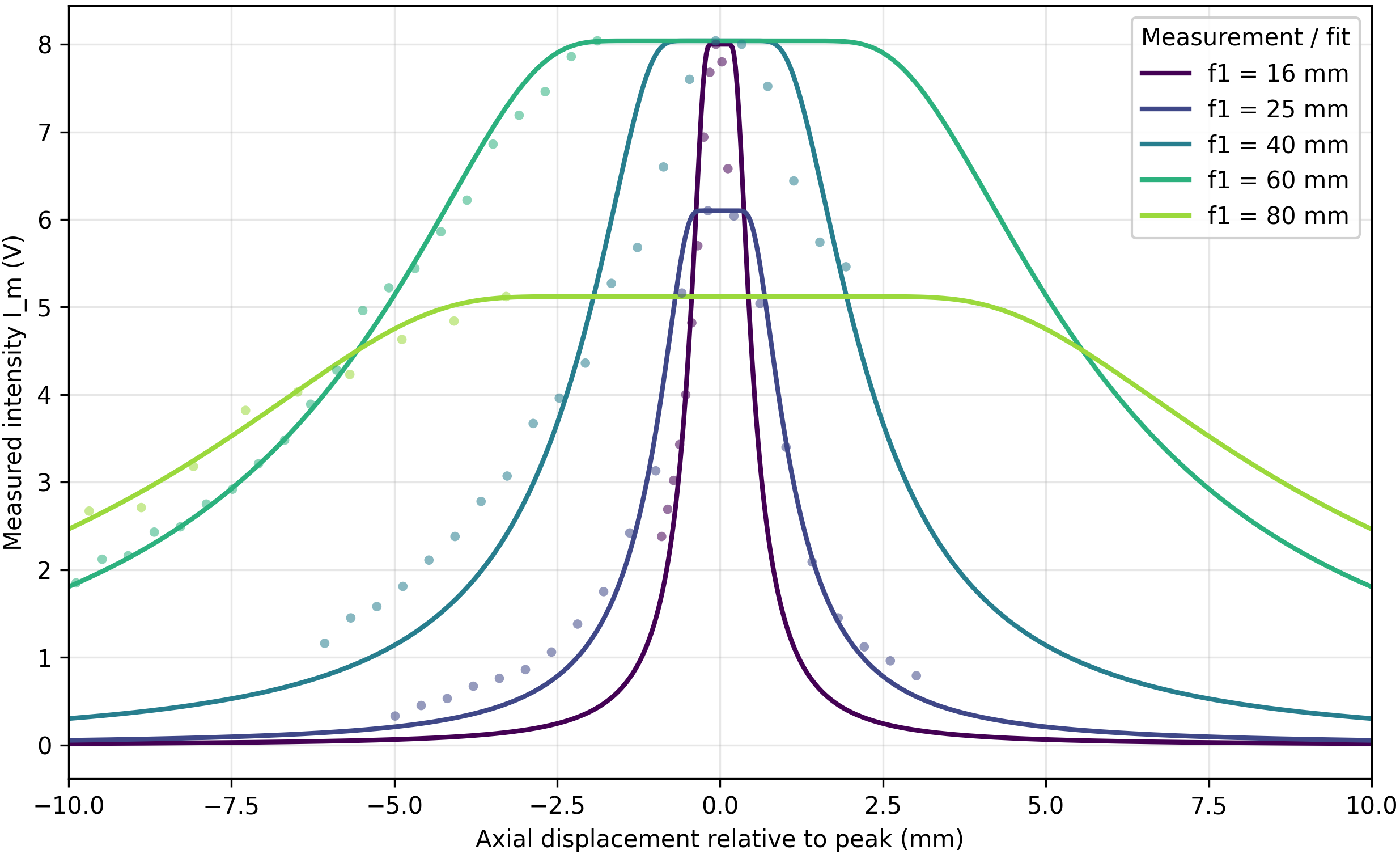
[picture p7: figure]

Fig. 5. Confocal response curves for different objective focal lengths, with the peak positions aligned at zero axial displacement.

Due to the difference in the theoretical and physical setup, the theoretical sensitivity and range do not match. Theoretically, the sensitivity is inverse-quadratically proportional (Sm ∝

1
f

2
1

). The measured data in table II, however, follows a relation of Sm ∝

1
f

1,64
1

TABLE II
MEASURED VS. THEORETICAL SENSITIVITY & LINEAR RANGE FOR DIFFERENT OBJECTIVE FOCAL LENGTHS.
f1 (mm) | Sm (V/mm) | Range (mm) | Sm,th (V/mm) | Rangeth (mm)
16 | 7,529 | 0,638 | 35,549 | 0,135
25 | 4,492 | 1,069 | 14,733 | 0,326
40 | 1,332 | 3,603 | 5,862 | 0,819
60 | 0,887 | 5,409 | 2,669 | 1,799
80 | 0,601 | 7,989 | 1,537 | 3,122

The same measurement principle can also be used for frequency analysis. Instead of recording only the average detector voltage at each position, the detector signal is recorded as a time-dependent signal. A frequency spectrum is then obtained from this signal by using the frequency analysis function in the oscilloscope software.

To verify the frequency analysis accuracy of the system, a stepper motor with a known speed has been used along with a 16 mm objective. Fig. 6 shows multiple frequency peaks at half or a quarter of the motor speed. From these results, it can be concluded that there is a linear correlation between the motor speed and the observed frequency peak.

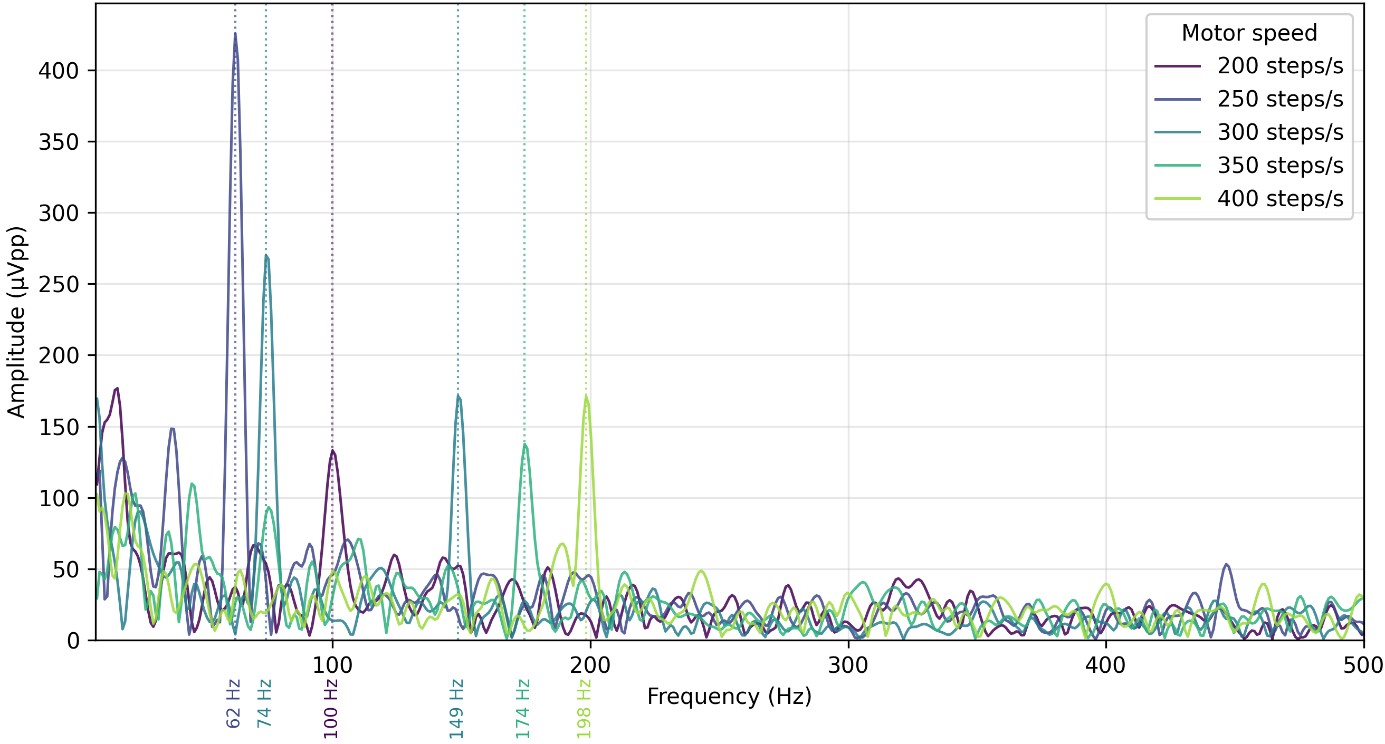
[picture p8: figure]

Fig. 6. Frequency spectra of the stepper motor recorded with the frequency analyser

The motor had the highest peak-to-peak value at a speed of 250 steps/s with a value of approximately 425 µV pp which amounts to an amplitude of 1, 46 µm using the linearized approximation.

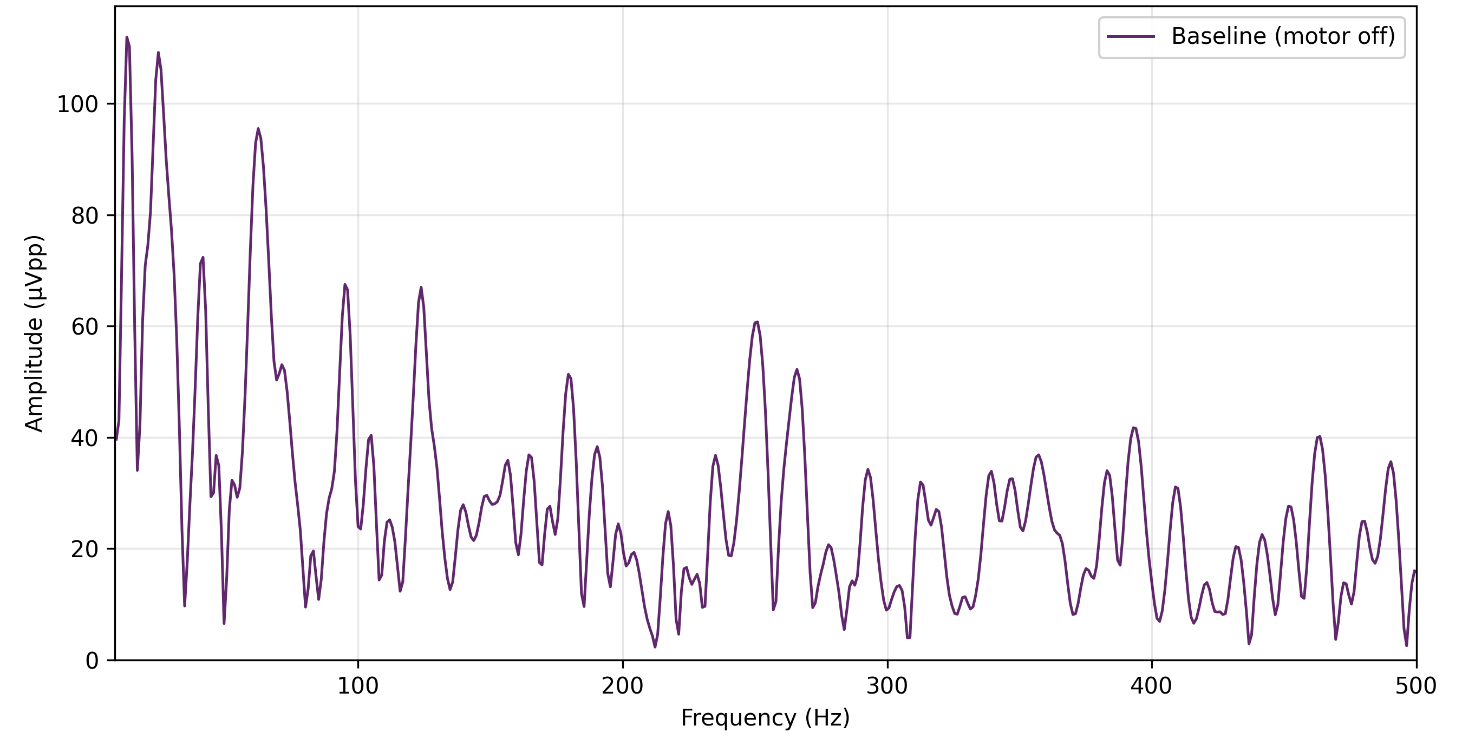
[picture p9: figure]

Fig. 7. Static noise measurement in the frequency domain

From taking a static measurement in the frequency domain with the same objective lens, the noise of the system has been deduced by taking the standard deviation of the amplitude over the entire signal (see Fig. 7). This value has been determined to be 105 nm. Using this standard deviation, the error of the stepper motor amplitude measurements is equal to 7,2%. Most of the noise is assumed to be electronic noise, which makes the setup less sensitive to noise when using larger objective focal lengths or a higher quality detector.

V. DISCUSSION
For all tested lens configurations, the overall shape of the measured response matched the predicted behaviour, confirming that the detector signal changes as a function of axial displacement, which also makes frequency measurements possible. There is, however, a difference in the theoretical and physical setup (see Fig. 4).

A likely cause of this disparity is the laser used in the setup. The theoretical model assumes an ideal Gaussian beam profile, while the laser used is far from a perfect Gaussian distribution. The parallelity of the laser is also imperfect. As a result, the effective detector spot size, intensity distribution and detector offset differ from the assumptions used in the model, leading to deviations between the predicted and measured responses. The increase in detector offset and mismatch with the power correlation (see Fig. 4 and Table II) can be explained by a slightly convergent laser. Despite these differences, the results are sufficient to demonstrate the validity of the confocal sensing principle for this application.

However, several limitations remain. First, the accuracy of the displacement estimation is currently limited by the error between the curve-fit and the measured reference points. Second, the method relies on sufficient reflected light reaching the detector. If the sample surface is not reflective enough or the sample lies at an angle, the detector signals may be too weak for reliable measurements.

Future work should focus on improving the laser used in the setup. Replacing the current laser with a low-cost laser that more closely approximates a Gaussian beam profile is expected to reduce the discrepancy between theory and experiment. This would provide a better assessment of the ultimate accuracy and applicability of the proposed sensing system. Further improvements could include a motorized tower, a hot-swappable f2 lens, and a variable beam radius for a larger range.

VI. CONCLUSION
This | paper | investigated | whether | a | cost-efficient
monochromatic confocal displacement sensing setup can measure displacements and vibrations over a tunable range for micro-engineering applications. A portable prototype was developed by integrating a confocal optical sensing tower with the OpenFlexure framework and a software-controlled measurement pipeline.

The results show that axial displacement can be measured through changes in detector voltage. By changing the objective focal length from 16 mm to 80 mm, the system demonstrated the expected trade-off between sensitivity and measurement range. Shorter focal lengths gave higher sensitivity over a smaller range, while longer focal lengths increased the usable range at the cost of sensitivity. Experimentally, the sensitivity varied from 7,529 V /mm to 0,601 V /mm, while the linear range increased from 0,638 mm to 7,989 mm.

The setup was also able to position the laser spot on a micro-scale AFM cantilever, showing that the optical path and OpenFlexure stage can be used for localised measurements on small structures. In addition, a first frequency-domain measurement was performed using a stepper motor. The largest measured amplitude was approximately 1,46 µm, with a noise-related error of 7,2%, demonstrating the potential of the system for vibration analysis.

It can therefore be concluded that a portable and cost-efficient confocal displacement sensing setup can be developed to measure displacements and vibrations over a tunable range. Since the setup could be aligned with an AFM cantilever, the system shows applicability for micro-engineering applications. Furthermore, the experimental results show that the system can measure displacements over a large range and that it is viable for vibration analysis.

REFERENCES

[1] D. Teyssieux, S. Euphrasie, and B. Cretin, “Mems in-plane motion/vibration measurement system based ccd camera,” Measurement, vol. 44, no. 10, pp. 2205–2216, 2011.
[2] Wenzel and Thomas, “Open hardware: From diy trend to global transformation in access to laboratory equipment,” PLOS Biology, vol. 21, no. 1, p. e3001931, 2023.
[3] R. H. Guis, U. Arabul, Z. Zhou, and G. J. Verbiest, “Monochromatic confocal displacement sensing for atomic force microscopy,” To be published, 2026/2027.
[4] J. T. Collins, J. Knapper, J. Stirling, J. Mduda, C. Mkindi, V. Mayagaya,
G. A. Mwakajinga, P. T. Nyakyi, V. L. Sanga, D. Carbery, L. White,
S. Dale, Z. J. Lim, J. J. Baumberg, P. Cicuta, S. McDermott, B. Vodenicharski, and R. Bowman, “Robotic microscopy for everyone: The openflexure microscope,” Biomedical Optics Express, vol. 11, no. 5, pp. 2447–2460, 2020.
[5] J. Li, R. Ma, and J. Bai, “High-precision chromatic confocal technologies: A review,” Micromachines, vol. 15, no. 10, p. 1224, 2024.
[6] J. Bai, X. Li, X. Wang, Q. Zhou, and K. Ni, “Chromatic confocal displacement sensor with optimized dispersion probe and modified centroid peak extraction algorithm,” Sensors, vol. 19, no. 16, p. 3592, 2019.

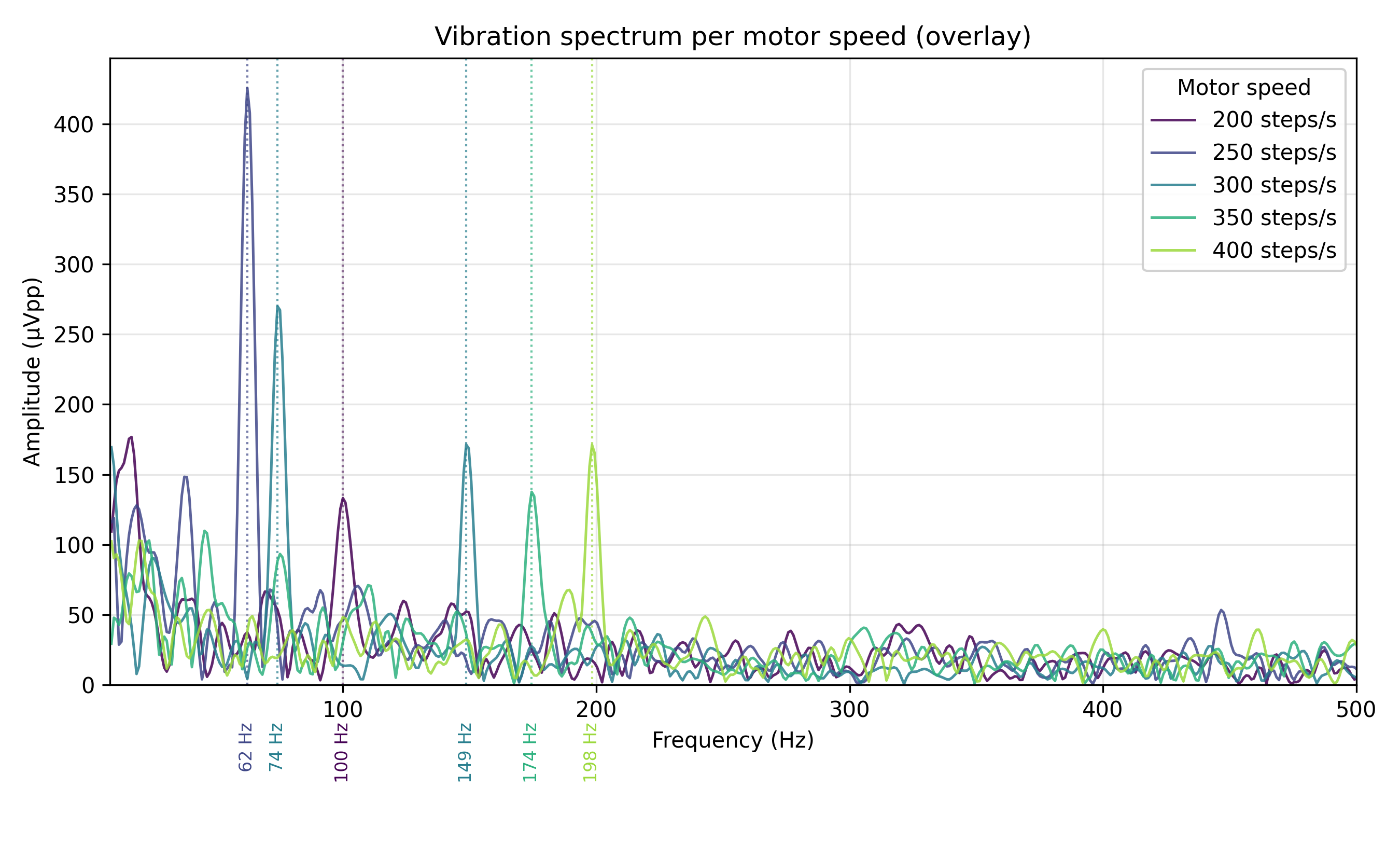
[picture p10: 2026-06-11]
assets/spectra_overlay.png

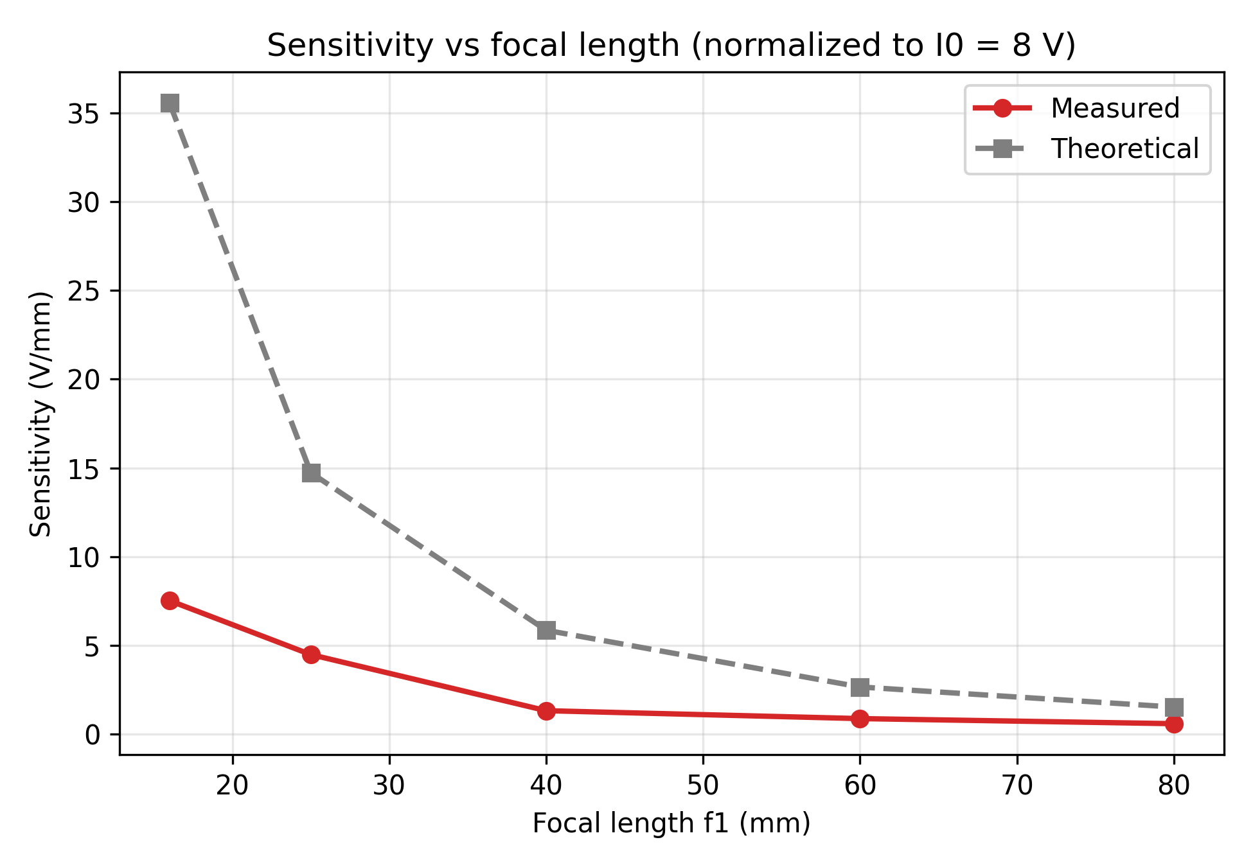
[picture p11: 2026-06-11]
assets/sensitivity_vs_f1.png

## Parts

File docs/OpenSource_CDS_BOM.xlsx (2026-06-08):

Name | Quantity | Full product name | Original purchase link/extra info | Cost
BASE_base | 1 |  | 1 kg black PLA (for all 3d prints) | €20.00
BASE_bridge | 1 |  |  | €0.00
BASE_electro | 1 |  |  | €0.00
BASE_electro_lid | 1 |  |  | €0.00
BASE_light_mount_base | 1 |  |  | €0.00
BASE_light_mount_swivel | 1 |  |  | €0.00
BASE_ruler | 1 |  |  | €0.00
BASE_switch_housing | 1 |  |  | €0.00
BASE_top_cap | 1 |  |  | €0.00
BLOCKS_camera_block | 1 |  |  | €0.00
BLOCKS_camera_cap | 1 |  |  | €0.00
BLOCKS_camera_nut_holder | 1 |  |  | €0.00
BLOCKS_cap | 2 |  |  | €0.00
BLOCKS_detector_block | 1 |  |  | €0.00
BLOCKS_detector_clamp | 1 |  |  | €0.00
BLOCKS_detector_q_slider | 1 |  |  | €0.00
BLOCKS_detector_side_slider | 1 |  |  | €0.00
BLOCKS_f1_block | 1 |  |  | €0.00
BLOCKS_f2_block | 1 |  |  | €0.00
BLOCKS_guide_spacer | 1 |  |  | €0.00
BLOCKS_laser_block | 1 |  |  | €0.00
BLOCKS_laser_cap | 1 |  |  | €0.00
BLOCKS_laser_spacer | 1 |  |  | €0.00
BLOCKS_lens_clamp | 2 |  |  | €0.00
BLOCKS_mirror_block | 2 |  |  | €0.00
BLOCKS_mirror_clamp_bottom | 2 |  |  | €0.00
BLOCKS_mirror_clamp_top | 1 |  |  | €0.00
BLOCKS_redfilter_clamp_top | 1 |  |  | €0.00
BLOCKS_spacer_0.4 | 1 |  |  | €0.00
BLOCKS_spacer_0.8 | 1 |  |  | €0.00
BLOCKS_spacer_1.2 | 1 |  |  | €0.00
BLOCKS_spacer_1.6 | 1 |  |  | €0.00
BLOCKS_spacer_2.0 | 1 |  |  | €0.00
BLOCKS_spacer_2.4 | 1 |  |  | €0.00
BLOCKS_spacer_2.8 | 1 |  |  | €0.00
BLOCKS_spacer_3.2 | 1 |  |  | €0.00
BLOCKS_spacer_box | 1 |  |  | €0.00
CALIBRATION_spacer_0.2 | 1 |  |  | €0.00
CALIBRATION_spacer_0.4 | 1 |  |  | €0.00
CALIBRATION_spacer_0.6 | 1 |  |  | €0.00
CALIBRATION_spacer_0.8 | 1 |  |  | €0.00
CALIBRATION_spacer_1 | 1 |  |  | €0.00
CALIBRATION_spacer_2 | 1 |  |  | €0.00
CALIBRATION_spacer_3 | 1 |  |  | €0.00
CALIBRATION_spacer_4 | 1 |  |  | €0.00
CALIBRATION_spacer_5 | 1 |  |  | €0.00
CALIBRATION_spacer_6 | 1 |  |  | €0.00
CALIBRATION_spacer_7 | 1 |  |  | €0.00
CALIBRATION_spacer_8 | 1 |  |  | €0.00
CALIBRATION_spacer_box | 1 |  |  | €0.00
CALIBRATION_table_calibrator | 1 |  |  | €0.00
Hex head screw M3x25 | 3 |  | ISO 4017 norm (price for all fasteners) | €10.00
Hex nut M2 | 4 |  | ISO 4032 norm | €0.00
Hex nut M3 | 40 |  | ISO 4032 norm | €0.00
Hex nut M6 | 6 |  | ISO 4032 norm | €0.00
Hex socket head cap screw M2x16 | 4 |  | ISO 4762 norm | €0.00
Hex socket head cap screw M3x12 | 34 |  | ISO 4762 norm | €0.00
Hex socket head cap screw M3x20 | 6 |  | ISO 4762 norm | €0.00
Hex socket head cap screw M3x6 | 13 |  | ISO 4762 norm | €0.00
Hex socket head cap screw M4x6 | 6 |  | ISO 4762 norm | €0.00
Hex socket head cap screw M6x20 | 8 |  | ISO 4762 norm | €0.00
Hex socket head cap screw M6x40 | 2 |  | ISO 4762 norm | €0.00
OEM_1080p_camera | 1 | Innomaker 1080P USB 2.0 UVC | link (https://www.amazon.nl/InnoMaker-UVC-camera-groothoekcamera-Raspberry-Ondersteunt/dp/B0CNCSFQC1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) | €18.59
OEM_28BYJ-48_stepper | 3 | 28BYJ-48 5V Stepper motor | link (https://www.amazon.nl/Stappenmotor-28BYJ-48-ULN2003-Driverboard-Arduino/dp/B01MEGIHLF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) | €14.44
OEM_arduino_nano | 1 | Every version of Arduino Nano viable | link (https://www.amazon.nl/-/en/Module-CH340-Microchip-Compatible-Arduino/dp/B0FDKM4B6Z) | €10.09
OEM_baseplate | 1 |  | Compatible with optical table (no cost) | €0.00
OEM_beam_splitter | 1 | EBS1 Economy 50:50 Beamsplitter | link (https://www.thorlabs.com/item/EBS1?utm_source=chatgpt.com) | €37.27
OEM_breakout_board | 1 | Nano V3.0 Terminal adapter board | link (https://www.amazon.nl/-/en/gp/product/B08T1ZXS7K/ref=ewc_pr_img_1?smid=A1X7QLRQH87QA3&th=1) | €6.49
OEM_cables_22AWG | 1 |  | link (https://www.amazon.nl/sourcing-map-Siliconendraad-elektrische-temperatuur/dp/B0CHVP1FM9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) | €8.82
OEM_DET10A2_detector | 1 | DET10A2 Detector | link (https://www.thorlabs.com/free-space-biased-detectors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) | €176.71
OEM_laser_5V | 1 | 10 PCS 5V Laser Diode Dot Red 650 nm, 5 V | link (https://www.amazon.nl/Aihasd-Laser-Head-Diode-Module/dp/B07H93XR1X?__mk_nl_NL=%C3%85M%C3%85%C5%BD%C3%95%C3%91) | €5.99
OEM_led_circle | 2 |  | link (https://www.amazon.nl/-/en/Heevhas-WS2812-Module-Accessories-Decoration/dp/B0DRHRQ2MW) | €4.97
OEM_lens_f100 | 1 | 25x10mm lens housing | Check thorlabs.com or other supplier for current pricing (approximate cost given) | €400.00
OEM_lens_f150 | 1 | 25x10mm lens housing | Check thorlabs.com or other supplier for current pricing (approximate cost given) | €0.00
OEM_lens_f25 | 1 | 25x10mm lens housing | Check thorlabs.com or other supplier for current pricing (approximate cost given) | €0.00
OEM_lens_f40 | 1 | 25x10mm lens housing | Check thorlabs.com or other supplier for current pricing (approximate cost given) | €0.00
OEM_lens_f-40 | 1 | 25x10mm lens housing | Check thorlabs.com or other supplier for current pricing (approximate cost given) | €0.00
OEM_lens_f60 | 1 | 25x10mm lens housing | Check thorlabs.com or other supplier for current pricing (approximate cost given) | €0.00
OEM_lens_f80 | 1 | 25x10mm lens housing | Check thorlabs.com or other supplier for current pricing (approximate cost given) | €0.00
OEM_moku_go | 1 | Moku:Go | link (https://liquidinstruments.com/product/moku-go/) | €689.01
OEM_red_light_filter | 1 | 25x6mm red reflecting filter | Check thorlabs.com or other supplier for current pricing (approximate cost given) | €150.00
OEM_rod_350mm | 2 | Lineaire as staaf gehard en geslepen met chroomlaag 8 x 350 mm | link (https://www.123-3d.nl/123-3D-Lineaire-as-staaf-gehard-en-geslepen-met-chroomlaag-8-x-350-mm-i1776.html) | €34.00
OEM_threaded_rod_150mm | 2 |  | ISO 4762 norm | €0.00
OEM_toggle_switch | 1 |  | link (https://www.amazon.nl/Tuimelschakelaar-Posities-Voertuig-Dashboard-donkerblauw/dp/B0B56S4F1X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) | €8.03
OEM_ULN2003_stepper_driver | 3 | ULN2003 stepper driver | Look at stepper motor link | €0.00
OEM_usb_5V_powercable | 2 |  | link (https://www.amazon.nl/Greluma-Pigtail-22AWG-Cable-Meters/dp/B0CWV5GSTY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) | €9.99
OEM_usb_B_cable | 1 | USB type B cable | Look at Arduino Nano link | €0.00
OEM_vitonrubber75_rings_30x2 | 3 | O-ring 30x2 - FKM - FPM - Viton - 75 Shore A - Zwart - ORS165428 | link (https://www.o-ring-stocks.eu/nl/o-ring-30x2-fkm-fpm-viton-75-shore-a-zwart-ors165428) | €1.71
Plain washer large M5 | 2 |  | ISO 7093 norm | €0.00
Plain washer M3 | 21 |  | DIN 125 norm | €0.00
Plain washer M6 | 4 |  | DIN 125 norm | €0.00
Prevailing torque nut M3 | 11 |  | DIN 985 norm | €0.00
STAGE_actuator_nut_tool | 1 |  |  | €0.00
STAGE_actuator_ring_tool | 1 |  |  | €0.00
STAGE_gear | 3 |  |  | €0.00
STAGE_main_base | 1 |  |  | €0.00
STAGE_main_body | 1 |  |  | €0.00
STAGE_moving_platform | 1 |  |  | €0.00
STAGE_small_gear | 3 |  |  | €0.00
TOTAL | 265 |  |  | €1606.11

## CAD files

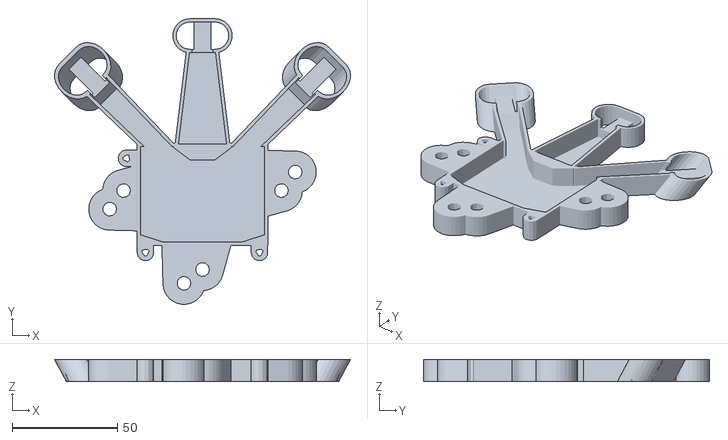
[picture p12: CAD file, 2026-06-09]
cad/stl/STAGE_main_base.stl
140.6 x 135.7 x 10.5

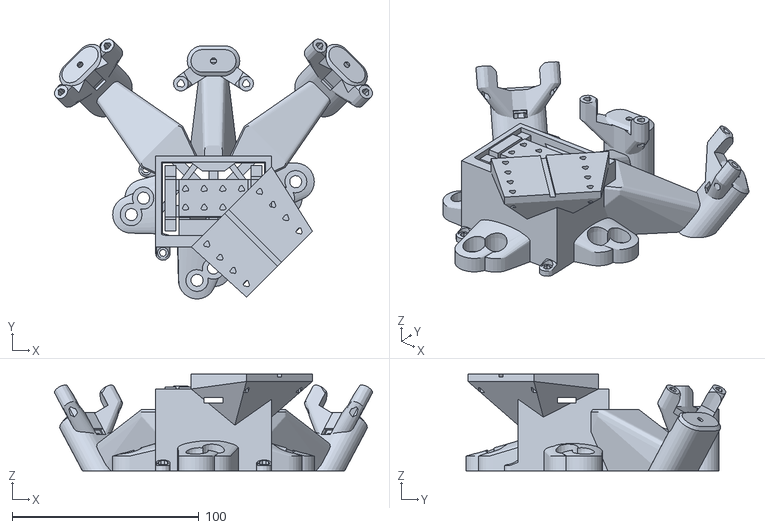
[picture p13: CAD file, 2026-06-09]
cad/stl/STAGE_main_body.stl
170.5 x 139.3 x 52.0

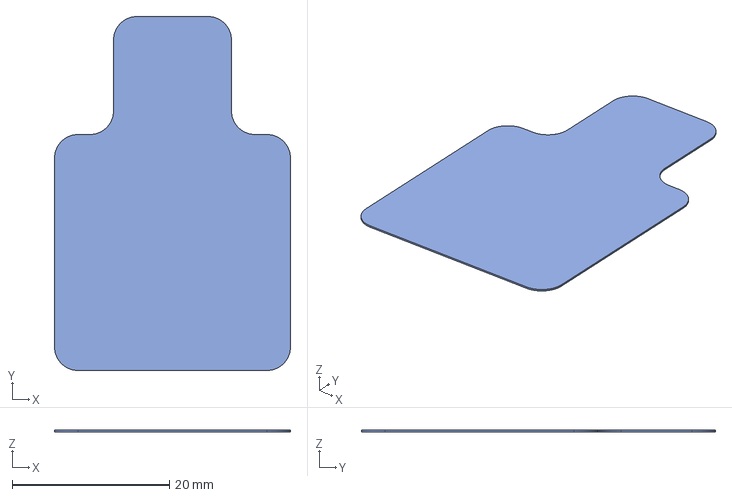
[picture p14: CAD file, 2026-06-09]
cad/step/CALIBRATION_spacer_0.2.step
30.0 x 45.0 x 0.2 mm

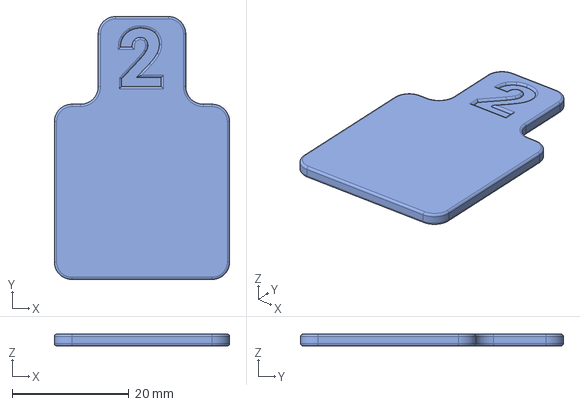
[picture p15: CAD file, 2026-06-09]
cad/step/CALIBRATION_spacer_2.step
30.0 x 45.0 x 2.00 mm

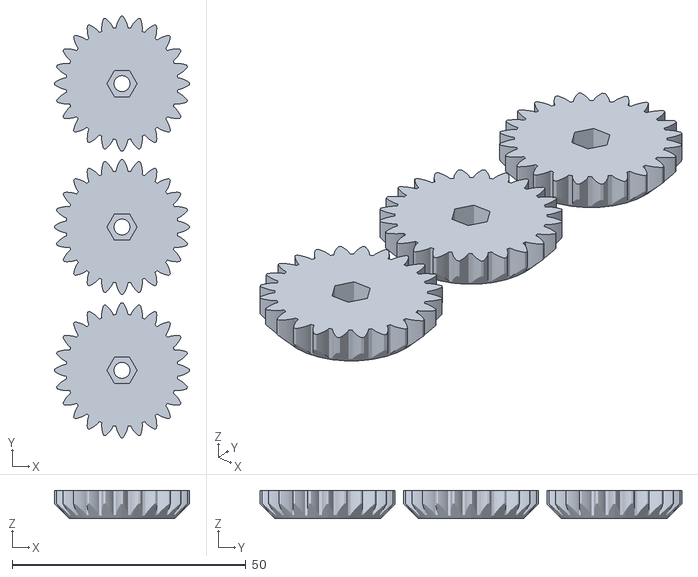
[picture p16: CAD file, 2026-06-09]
cad/stl/STAGE_gears.stl
28.9 x 90.2 x 6.00

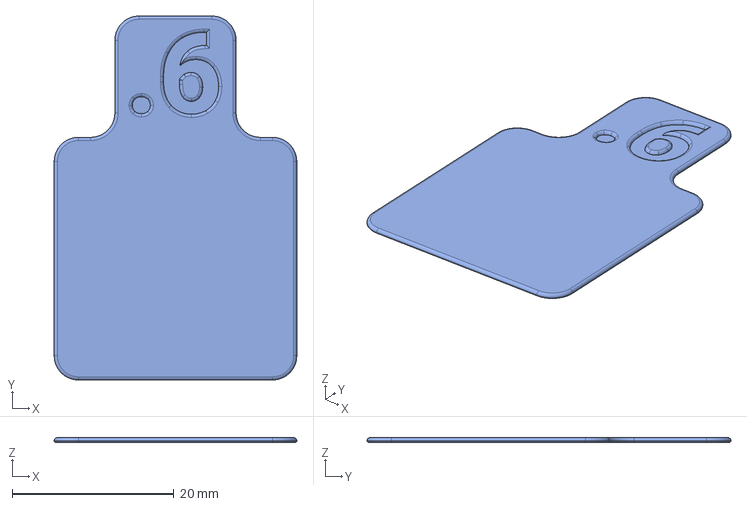
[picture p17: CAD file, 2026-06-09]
cad/step/CALIBRATION_spacer_0.6.step
30.0 x 45.0 x 0.6 mm

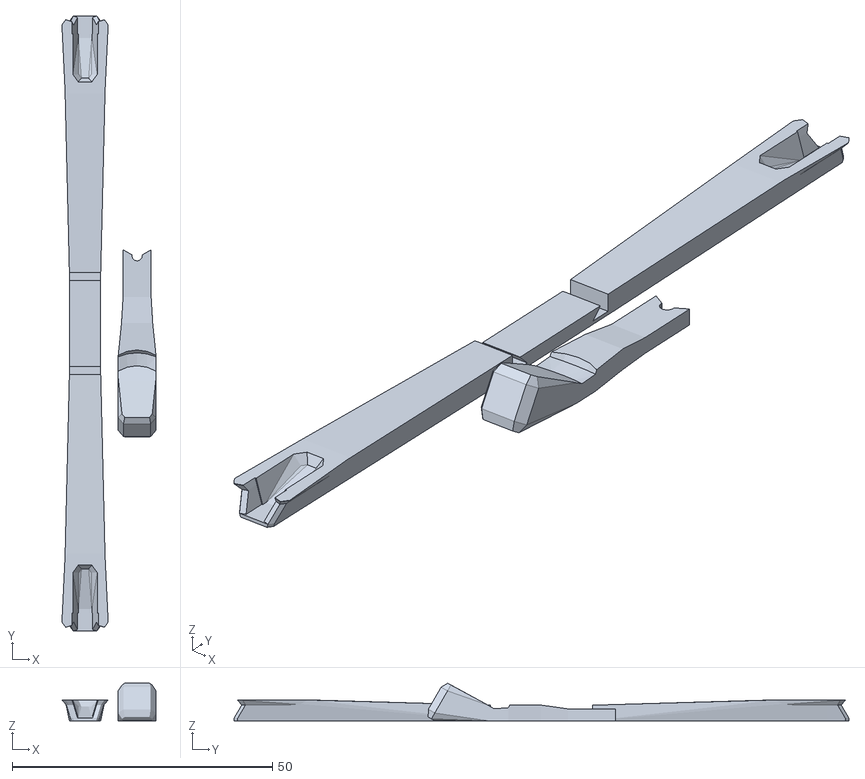
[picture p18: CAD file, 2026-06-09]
cad/stl/STAGE_actuator_tools.stl
18.1 x 118.2 x 7.23

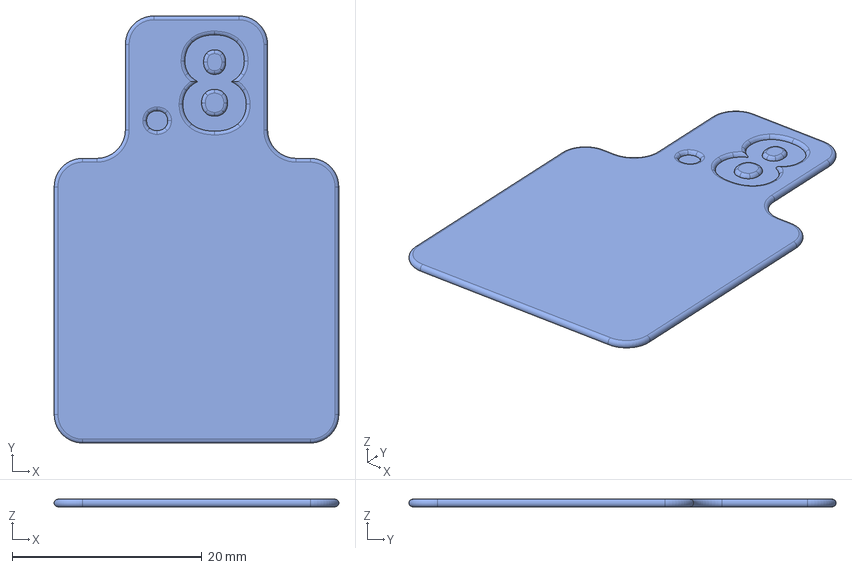
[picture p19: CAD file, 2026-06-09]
cad/step/CALIBRATION_spacer_0.8.step
30.0 x 45.0 x 0.8 mm

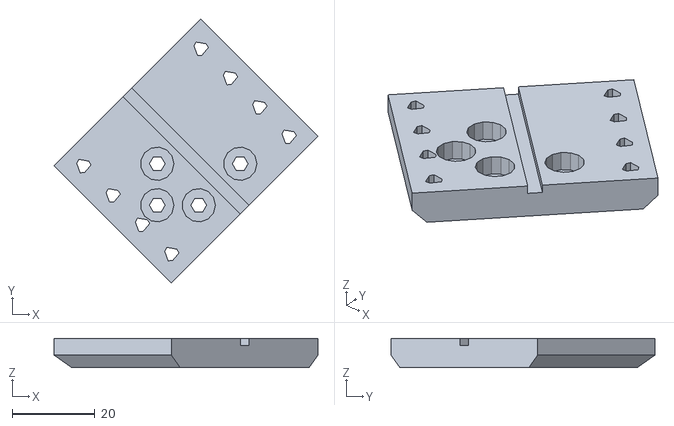
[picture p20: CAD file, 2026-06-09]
cad/stl/STAGE_moving_platform.stl
63.6 x 63.6 x 7.00

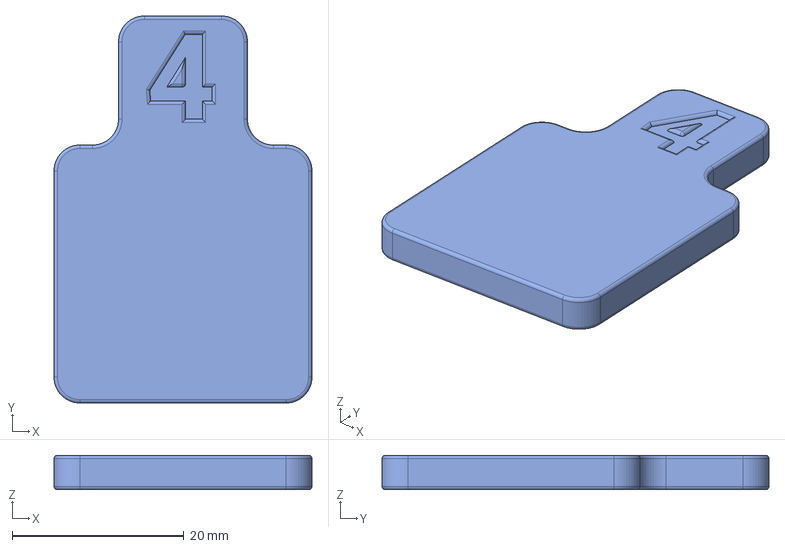
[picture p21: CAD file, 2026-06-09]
cad/step/CALIBRATION_spacer_4.step
30.0 x 45.0 x 4.00 mm

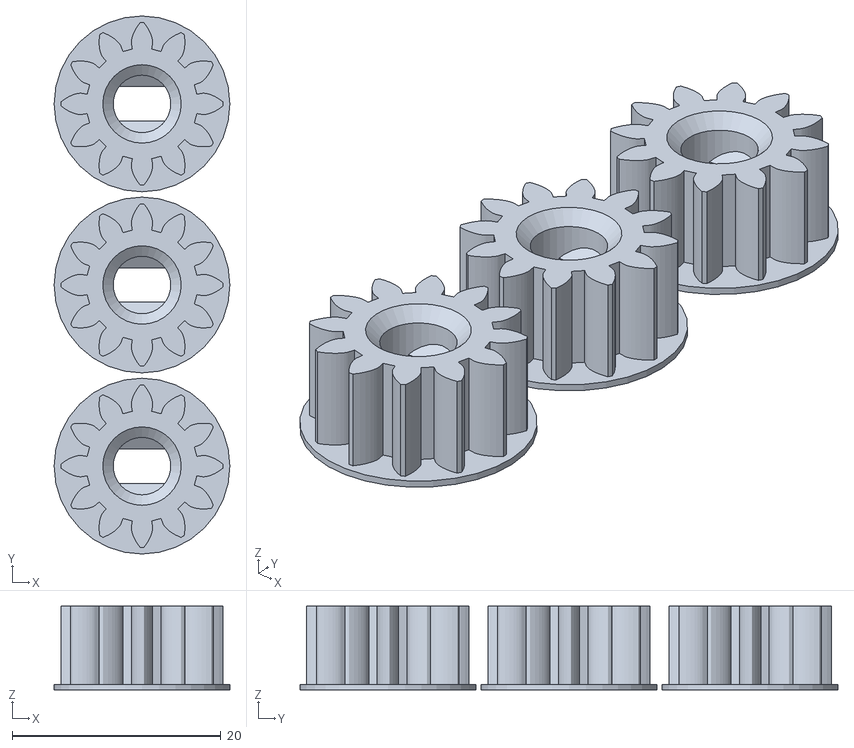
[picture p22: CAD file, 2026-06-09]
cad/stl/STAGE_small_gears.stl
16.8 x 51.5 x 8.00

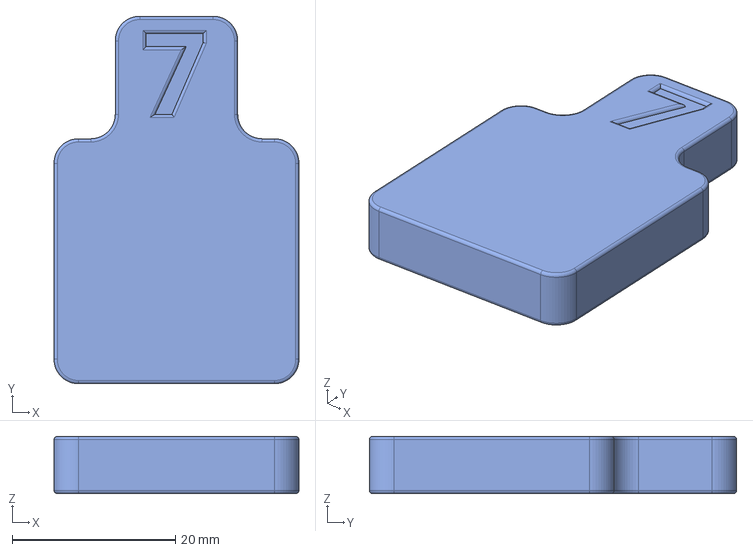
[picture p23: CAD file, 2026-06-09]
cad/step/CALIBRATION_spacer_7.step
30.0 x 45.0 x 7.00 mm

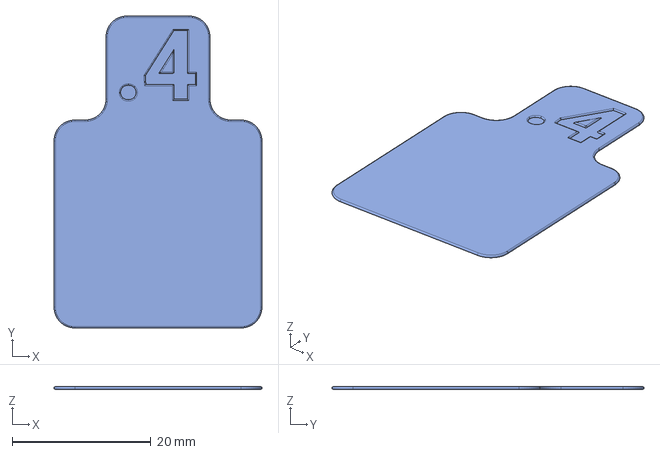
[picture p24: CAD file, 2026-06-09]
cad/step/CALIBRATION_spacer_0.4.step
30.0 x 45.0 x 0.4 mm

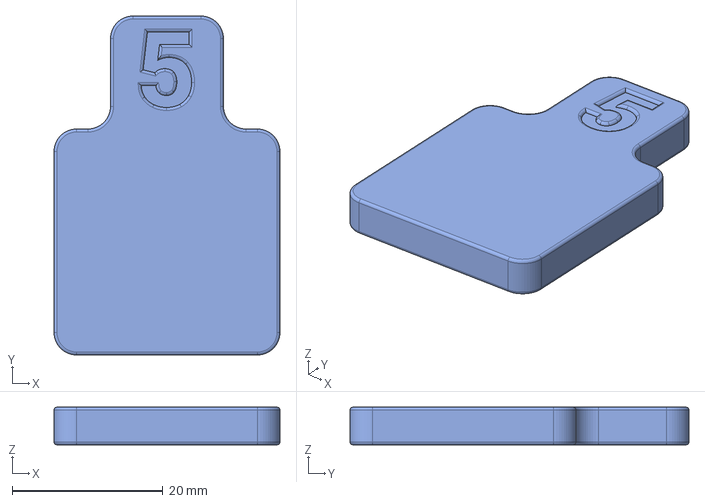
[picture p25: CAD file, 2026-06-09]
cad/step/CALIBRATION_spacer_5.step
30.0 x 45.0 x 5.00 mm

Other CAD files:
cad/step/CALIBRATION_spacer_6.step
cad/step/CALIBRATION_spacer_box.step
cad/step/CALIBRATION_spacer_8.step
cad/step/CALIBRATION_spacer_3.step
cad/step/BASE_base.step
cad/step/BASE_bridge.step
cad/step/BASE_electro.step
cad/step/BASE_electro_lid.step
cad/step/BASE_light_mount_base.step
cad/step/BASE_light_mount_swivel.step
cad/step/BASE_ruler.step
cad/step/BASE_switch_housing.step
cad/step/BASE_top_cap.step
cad/step/BLOCKS_camera_block.step
cad/step/BLOCKS_camera_cap.step
cad/step/BLOCKS_camera_nut_holder.step
cad/step/BLOCKS_cap.step
cad/step/BLOCKS_detector_block.step
cad/step/BLOCKS_detector_clamp.step
cad/step/BLOCKS_detector_q_slider.step
cad/step/BLOCKS_detector_side_slider.step
cad/step/BLOCKS_f1_block.step
cad/step/BLOCKS_f2_block.step
cad/step/BLOCKS_guide_spacer.step
cad/step/BLOCKS_laser_block.step
cad/step/BLOCKS_laser_cap.step
cad/step/BLOCKS_laser_spacer.step
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

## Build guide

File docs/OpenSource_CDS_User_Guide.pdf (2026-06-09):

# OpenSource CDS | User Guide

# Documentation on functionality and calibration

### Project name: BEP PME-A06 Version: v1.0 Date: June 9, 2026

OpenSource CDS | User Guide | 1

# Content

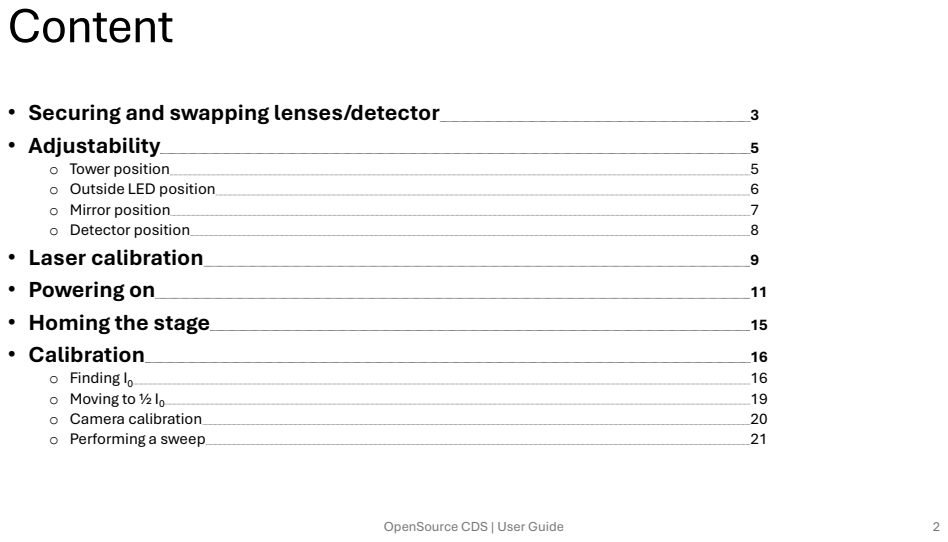
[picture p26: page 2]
• Securing and swapping lenses/detector; • Adjustability; • Tower position; • Outside LED position; • Mirror position; • Detector position; • Laser calibration; • Powering on; • Homing the stage; • Calibration; • Finding I0; • Moving to ½ I0; • Camera calibration; • Performing a sweep

# Securing and swapping lenses/detector

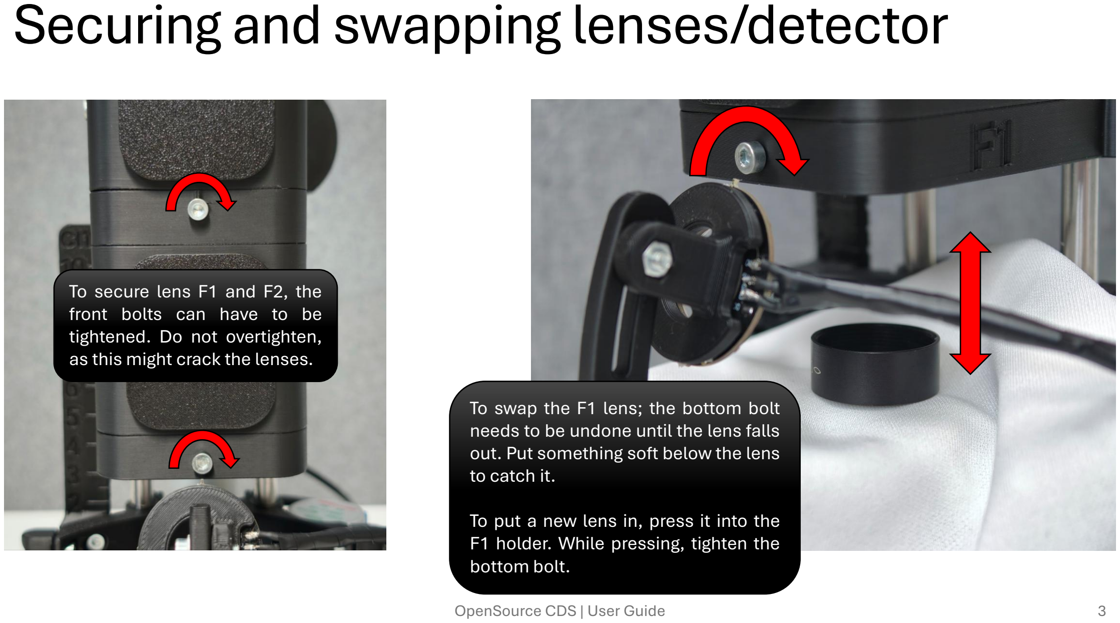
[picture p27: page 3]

To secure lens F1 and F2, the front bolts can have to be tightened. Do not overtighten, as this might crack the lenses.

To swap the F1 lens; the bottom bolt needs to be undone until the lens falls out. Put something soft below the lens to catch it.

To put a new lens in, press it into the F1 holder. While pressing, tighten the bottom bolt.

# Securing and swapping lenses/detector

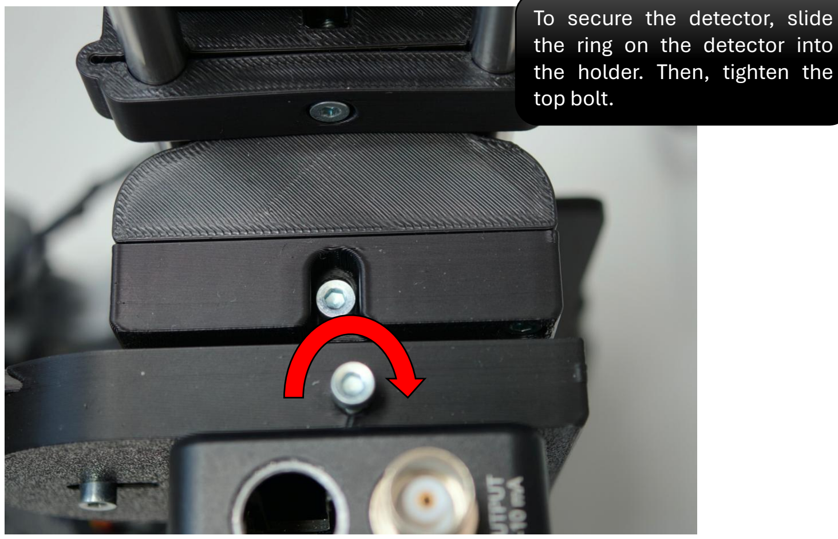
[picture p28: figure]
To secure the detector, slide the ring on the detector into the holder. Then, tighten the top bolt.

# Adjustability | Tower position

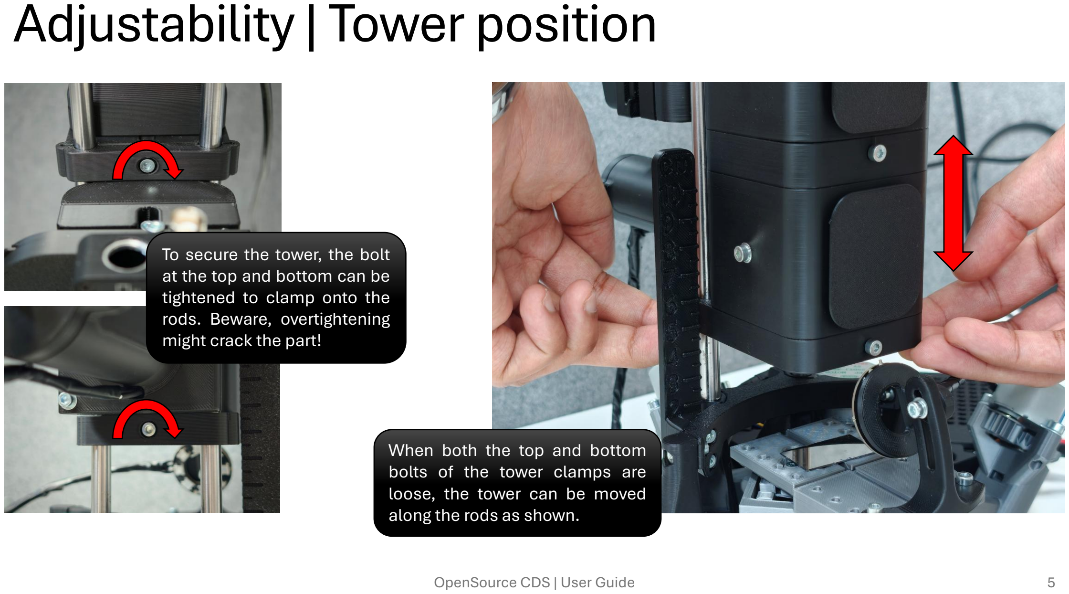
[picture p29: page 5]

To secure the tower, the bolt at the top and bottom can be tightened to clamp onto the rods. Beware, overtightening might crack the part!

When both the top and bottom bolts of the tower clamps are loose, the tower can be moved along the rods as shown.

# Adjustability | Outside LED position

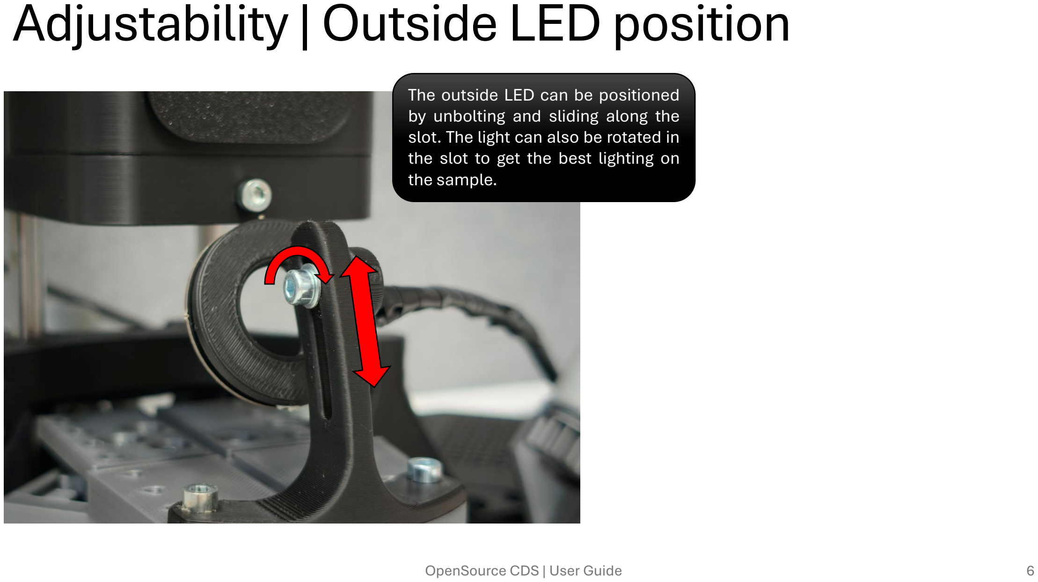
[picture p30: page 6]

The outside LED can be positioned by unbolting and sliding along the slot. The light can also be rotated in the slot to get the best lighting on the sample.

# Adjustability | Mirror position

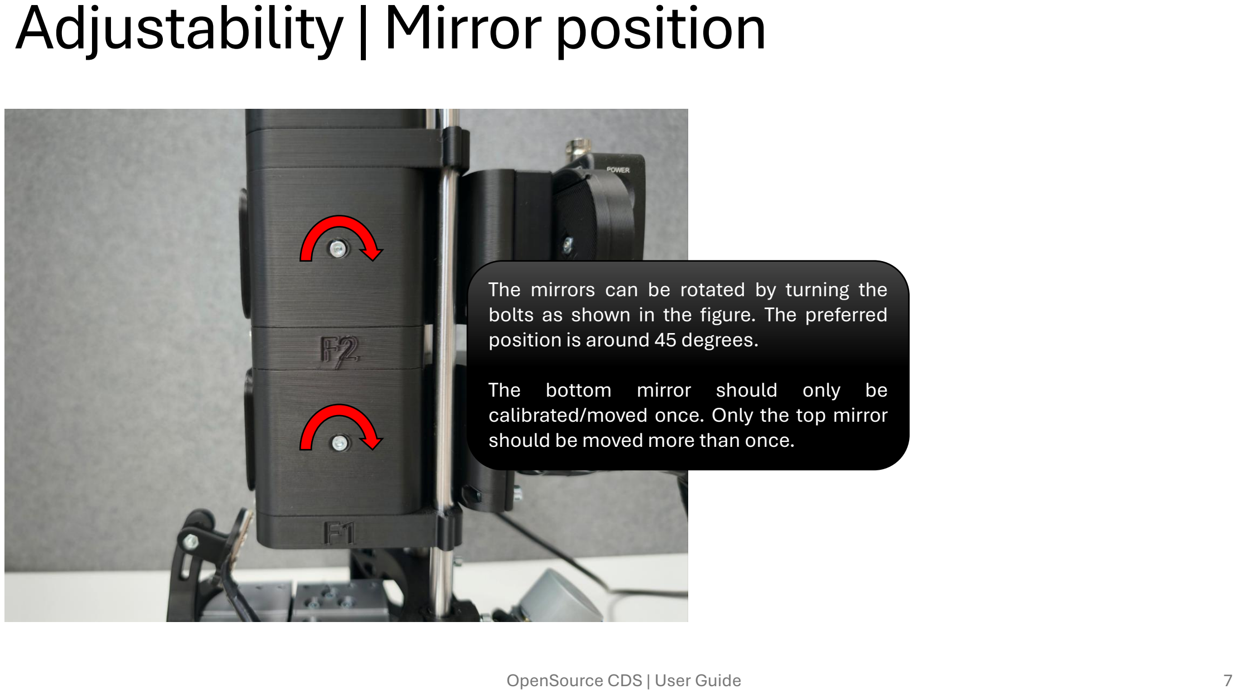
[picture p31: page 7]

The mirrors can be rotated by turning the bolts as shown in the figure. The preferred position is around 45 degrees.

The bottom mirror should only be calibrated/moved once. Only the top mirror should be moved more than once.

# Adjustability | Detector position

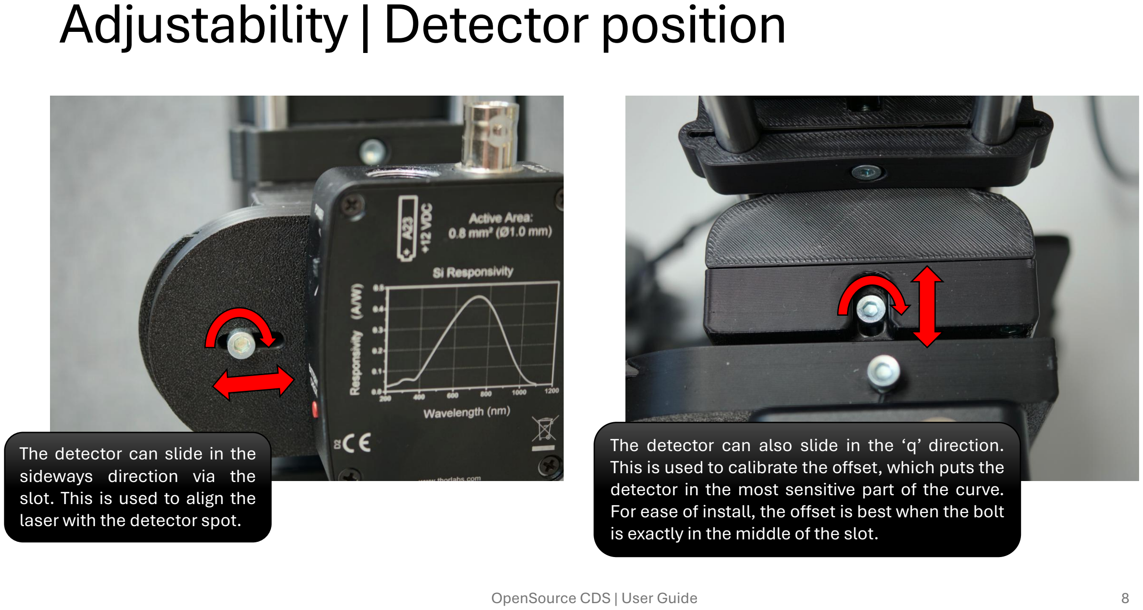
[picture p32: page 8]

The detector can slide in the sideways direction via the slot. This is used to align the laser with the detector spot.

The detector can also slide in the ‘q’ direction. This is used to calibrate the offset, which puts the detector in the most sensitive part of the curve. For ease of install, the offset is best when the bolt is exactly in the middle of the slot.

# Laser calibration

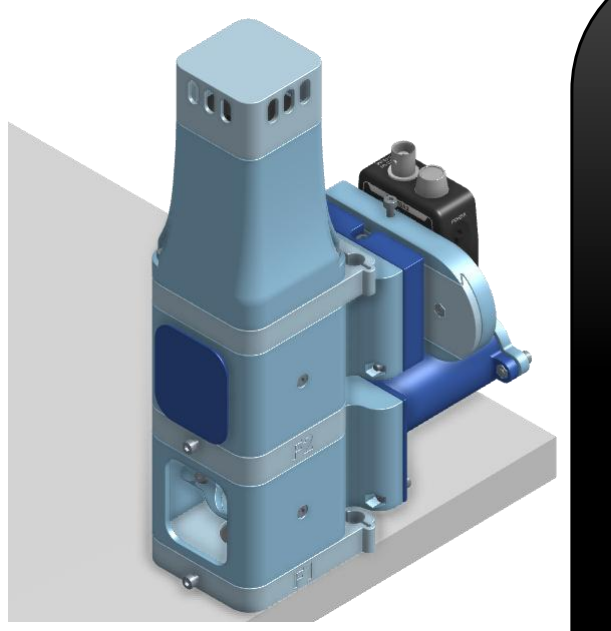
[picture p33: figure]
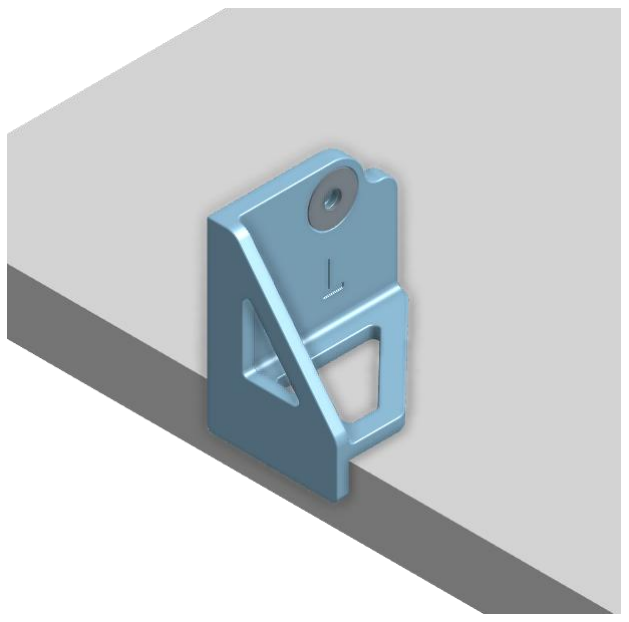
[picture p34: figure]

To get the laser as straight as possible, the table calibrator (with an M5 ring) should be placed on the edge of a table. On the other side, the tower assembly (without the bottom cap and semi-transparent mirror) should be placed with its edge lined up with the table.

When this is in place, wiggle the laser sideways, until the laser is roughly aligned with the hole in the table calibrator. After, rotate the end of the laser to create a parallel beam. The beam is parallel when the laser spot is the same size as the inner diameter of the M5 ring.

When the laser is approximately in the right position, glue it down to prevent misalignment.

# Laser calibration

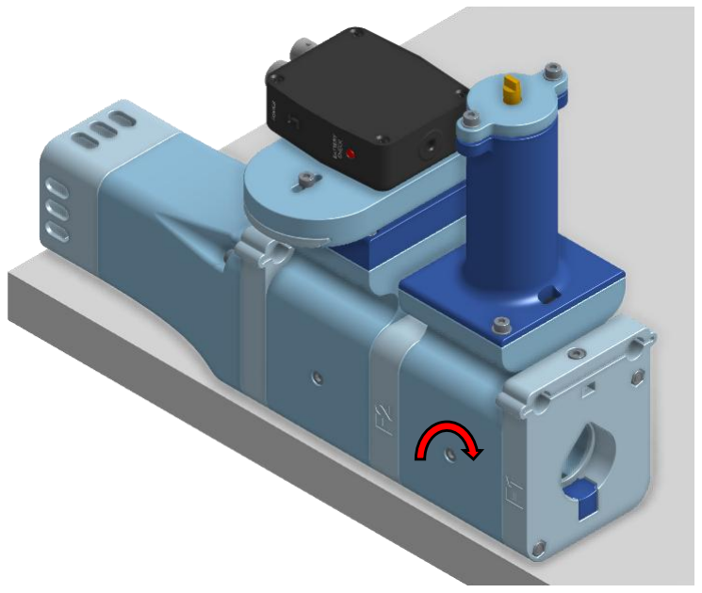
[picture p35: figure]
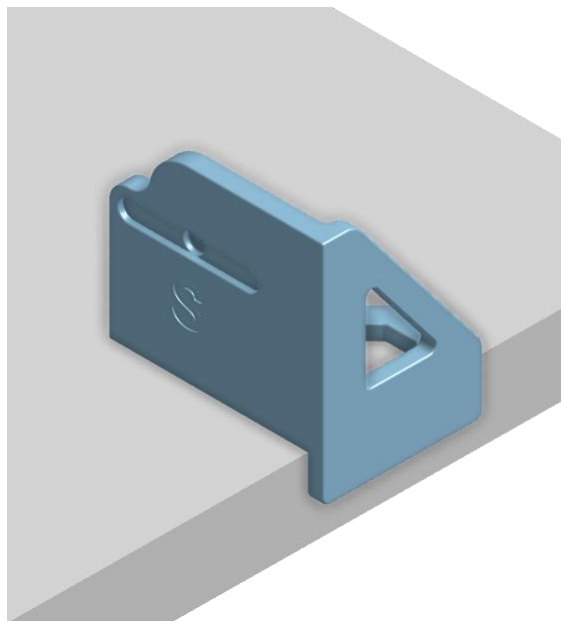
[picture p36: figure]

When the laser is fully aligned, the bottom semi-transparent mirror can be calibrated. This is done by removing the F1 and F2 lenses, with its corresponding bolts. The bottom semi-transparent mirror should be mounted back into the system.

When also the two front caps are removed, the tower is aligned with the edge of the table (on the other side). The table calibrator is flipped and placed on the other end.

Now, by rotating the bottom bolt, the beam can be focused onto the calibrator. When the beam is at the same height as the slot (on the calibrator), the beam is exactly reflected at an angle of 90 degrees.

# Powering on

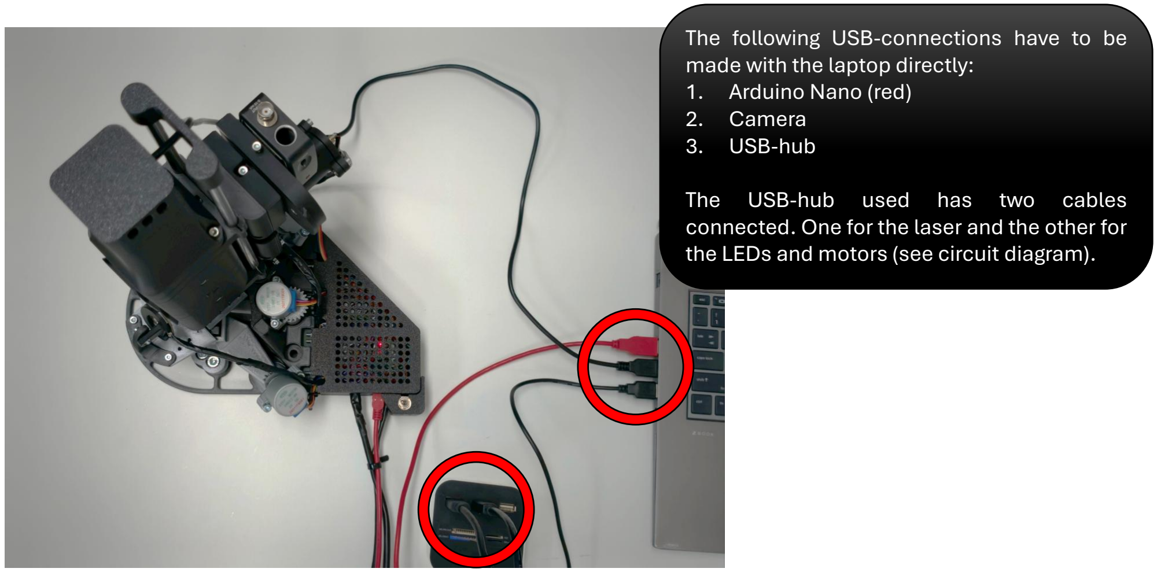
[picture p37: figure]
made with the laptop directly: 1. Arduino Nano (red) 2. Camera 3. USB-hub; The USB-hub used has two cables

The following USB-connections have to be

connected. One for the laser and the other for the LEDs and motors (see circuit diagram).

# Powering on

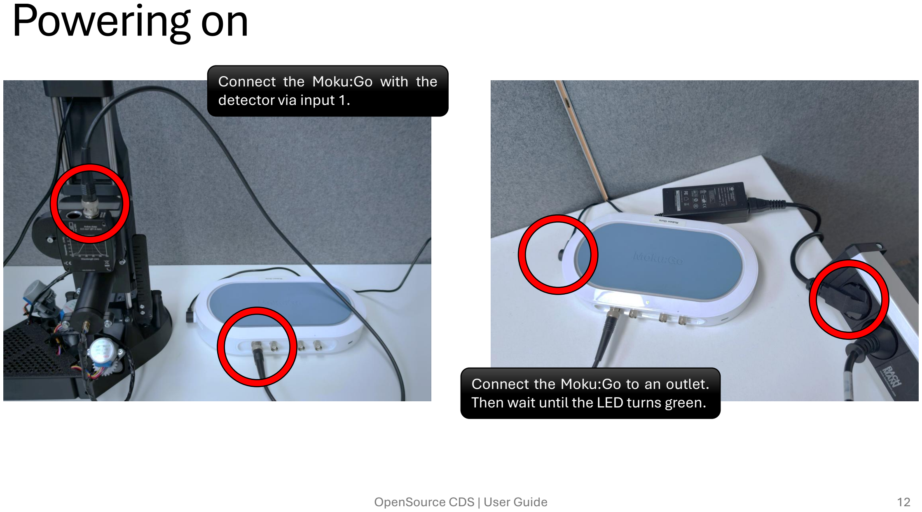
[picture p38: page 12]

Connect the Moku:Go with the detector via input 1.

Connect the Moku:Go to an outlet. Then wait until the LED turns green.

# Powering on

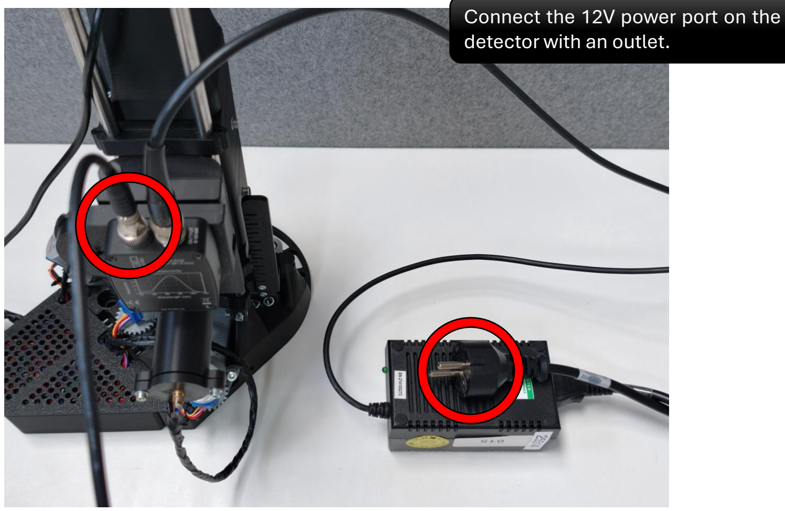
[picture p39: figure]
Connect the 12V power port on the detector with an outlet.

# Powering on

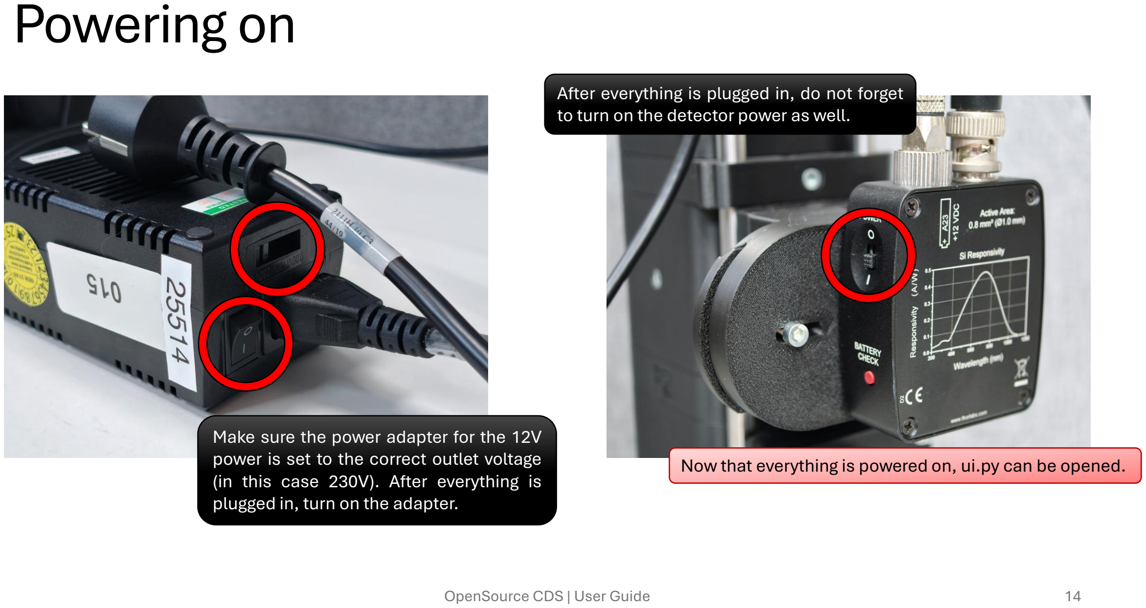
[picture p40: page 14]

Make sure the power adapter for the 12V power is set to the correct outlet voltage (in this case 230V). After everything is plugged in, turn on the adapter.

After everything is plugged in, do not forget to turn on the detector power as well.

Now that everything is powered on, ui.py can be opened.

# Homing the stage

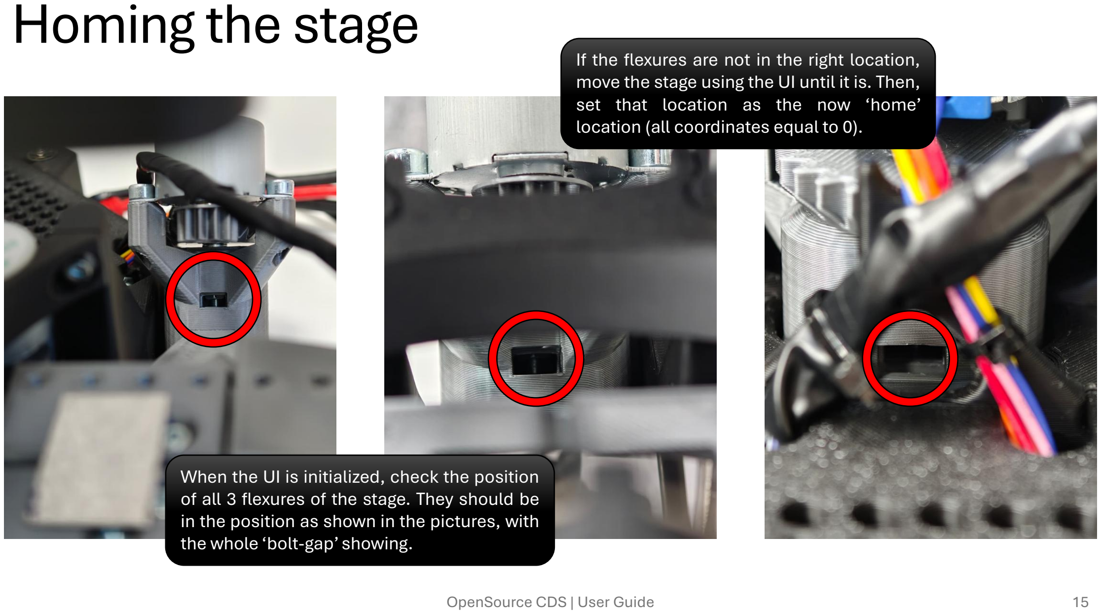
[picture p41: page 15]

When the UI is initialized, check the position of all 3 flexures of the stage. They should be in the position as shown in the pictures, with the whole ‘bolt-gap’ showing.

If the flexures are not in the right location, move the stage using the UI until it is. Then, set that location as the now ‘home’ location (all coordinates equal to 0).

# Calibration | Finding I0

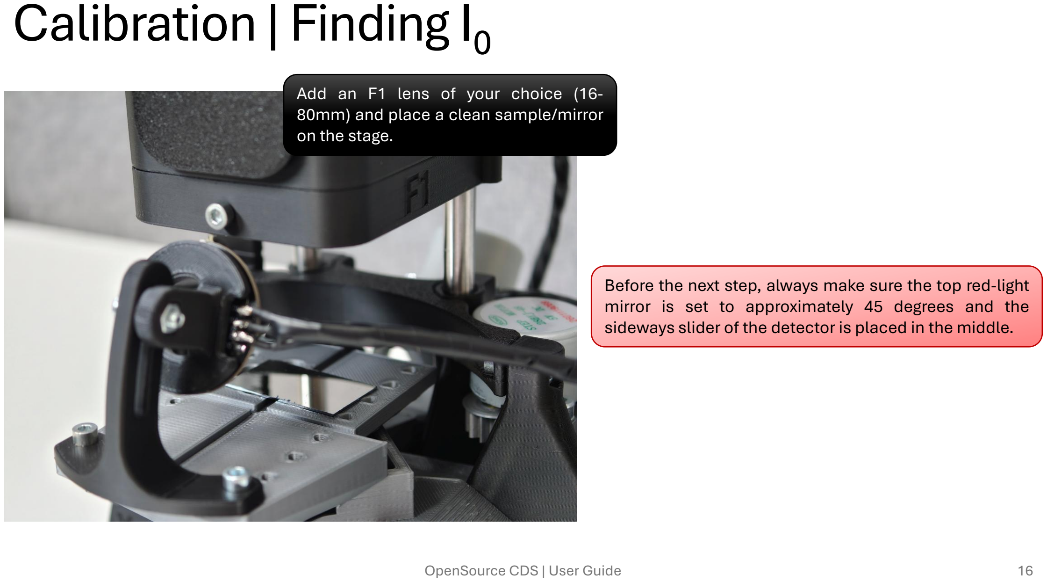
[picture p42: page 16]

Add an F1 lens of your choice (16-80mm) and place a clean sample/mirror on the stage.

Before the next step, always make sure the top red-light mirror is set to approximately 45 degrees and the sideways slider of the detector is placed in the middle.

# Calibration | Finding I0

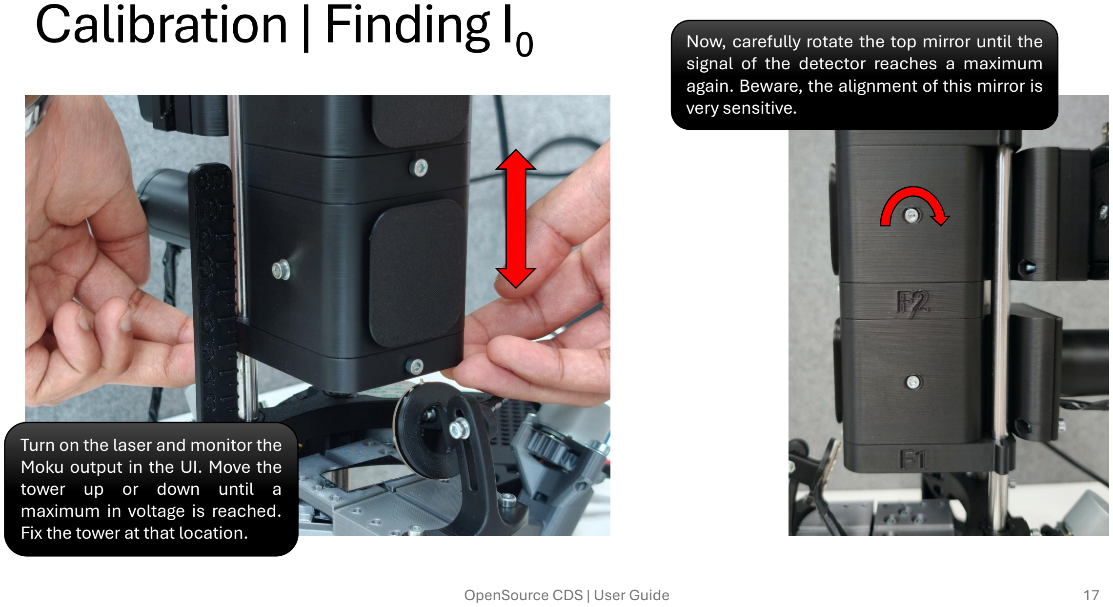
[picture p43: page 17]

Turn on the laser and monitor the Moku output in the UI. Move the tower up or down until a
maximum in voltage is reached. Fix the tower at that location.

Now, carefully rotate the top mirror until the signal of the detector reaches a maximum again. Beware, the alignment of this mirror is very sensitive.

# Calibration | Finding I0

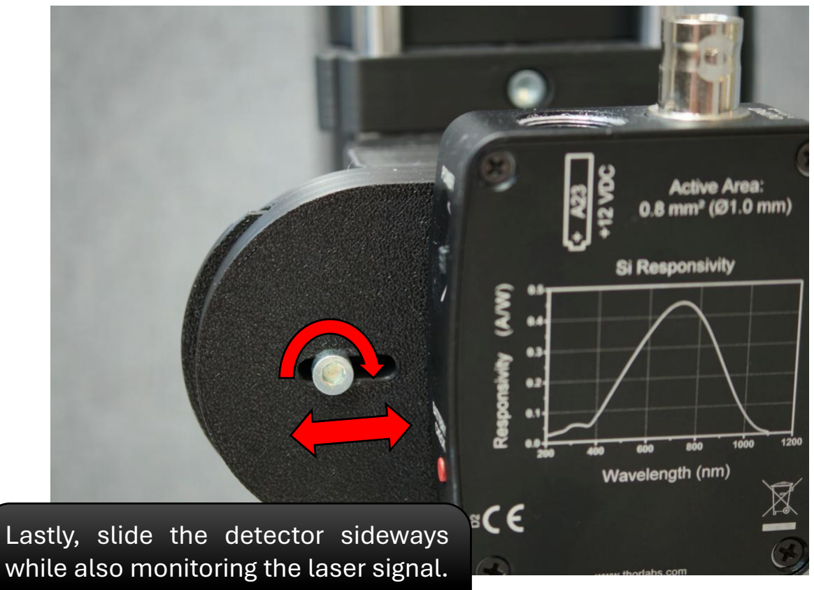
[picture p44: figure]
Lastly, slide the detector sideways while also monitoring the laser signal.

Make sure to tighten the bolt when the detector is in the right spot.

To check if the maximum intensity has been found, the tower can be moved up and down again (without rotating the mirror or moving the detector). When the maximum voltage is reached, its value should be written down (as well as put into ui.py).

# Calibration | Moving to ½ I0

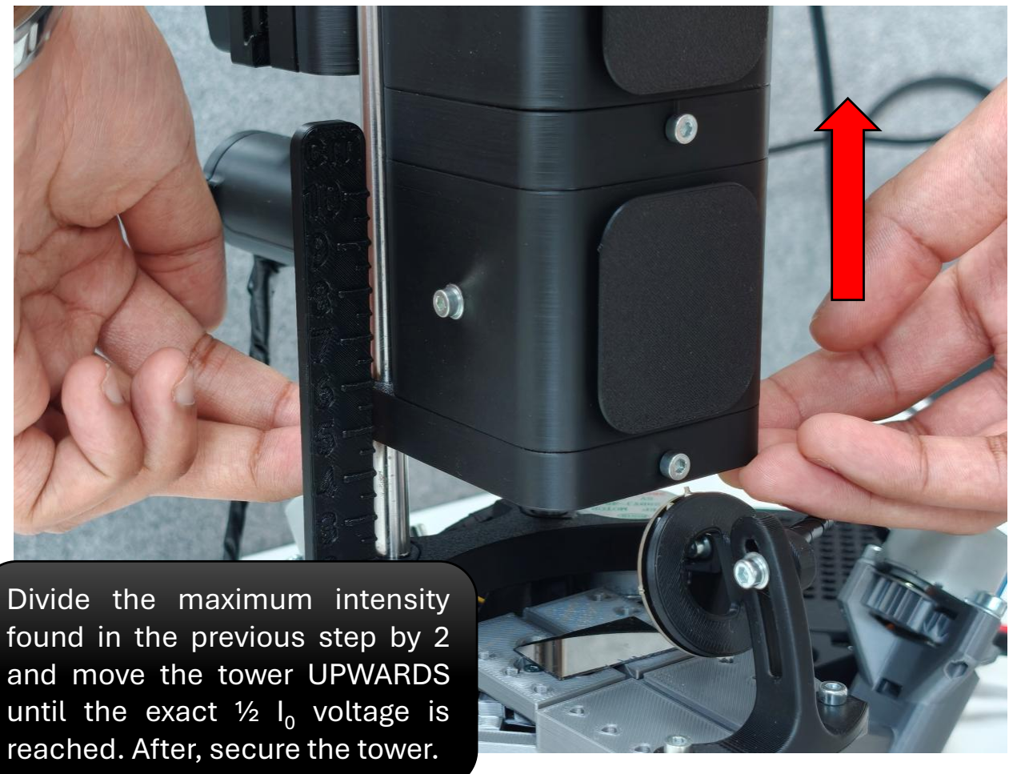
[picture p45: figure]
Divide the maximum intensity found in the previous step by 2 and move the tower UPWARDS until the exact ½ I0; voltage is reached. After, secure the tower.

# Calibration | Camera calibration

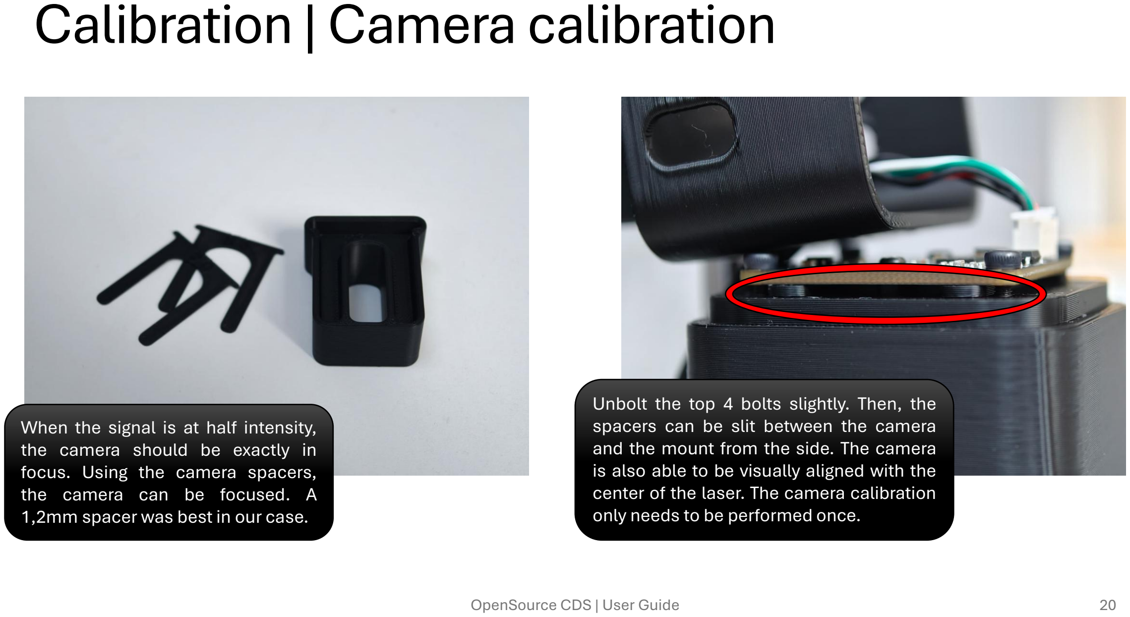
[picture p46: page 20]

When the signal is at half intensity, the camera should be exactly in focus. Using the camera spacers, the camera can be focused. A 1,2mm spacer was best in our case.

Unbolt the top 4 bolts slightly. Then, the spacers can be slit between the camera and the mount from the side. The camera is also able to be visually aligned with the center of the laser. The camera calibration only needs to be performed once.

# Calibration | Performing a sweep

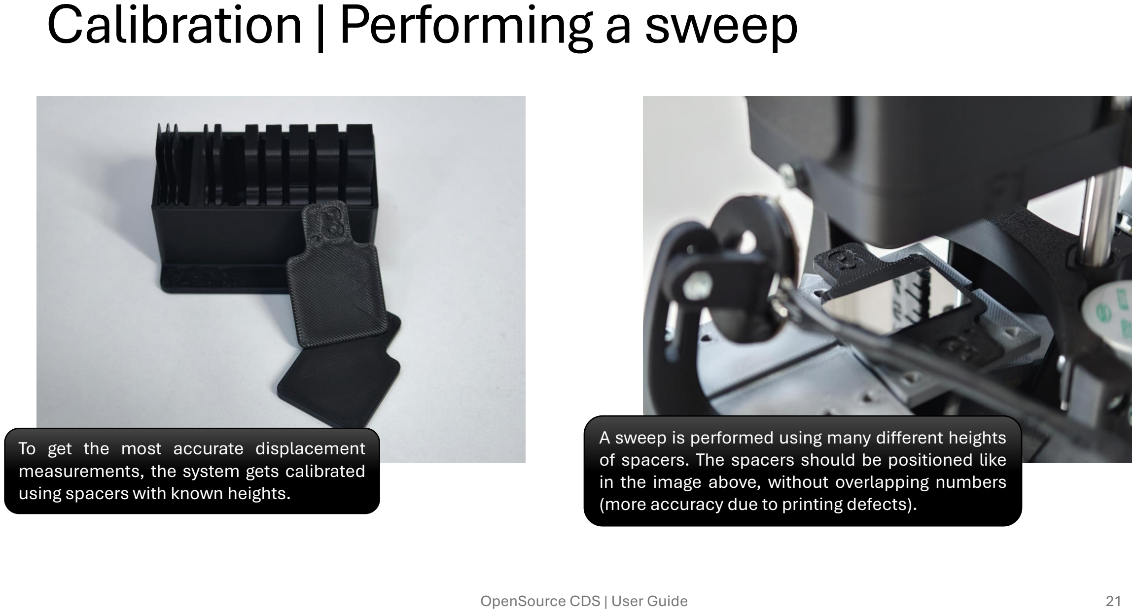
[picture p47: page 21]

To get the most accurate displacement measurements, the system gets calibrated using spacers with known heights.

A sweep is performed using many different heights of spacers. The spacers should be positioned like in the image above, without overlapping numbers (more accuracy due to printing defects).

# Calibration | Performing a sweep

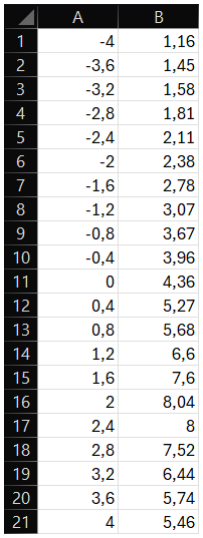
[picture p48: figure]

To start of the sweep, position the 4mm spacer and a mirror on top on the stage. Then, move the tower to find I0

(and align the top mirror and detector if needed). After, move the tower to ½ I0

Now, open an empty Excel document (or csv editor) and create two columns. The first column being the spacer height value, and the second column being the measured output voltage of the detector.

Set the 4mm spacer equal to a height of 0 and add the corresponding voltage value to the table. Now, switch out the spacers in steps of 0,4 or 0,2mm (depending on the size of F1) and measure the voltage at each height. This will create a result as shown in the picture on the left. This is a sweep with steps of 0,4mm with an F1 lens of 40mm.

The Excel document will be used in the ui.py to calibrate the displacement measurements. Only one sweep per F1 lens needs to be performed.

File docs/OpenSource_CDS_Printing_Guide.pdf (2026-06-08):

OpenSource CDS | Printing Guide | 1

# OpenSource CDS | Printing Guide

## Self-Printing Documentation

Project name: BEP PME-A06

Version: v1.0

Date: June 1, 2026

This document contains the recommended print settings and part overview for printing all required components of the OpenSource CDS.

OpenSource CDS | Printing Guide | 2

## General Print Requirements/Settings

The parts in this project are designed for standard FDM/FFF 3D printing. All parts can be printed using a single 1 kg roll of filament. A dark, low reflective filament colour is recommended for best results.
Unless stated otherwise for a specific part, use the following settings as a starting point.
Printer type | FDM / FFF 3D printer
Material | PLA recommended, PETG optional for stronger parts
Nozzle diameter | 0.4 mm
Layer height | 0.20 mm
Wall count | 2 walls
Top / bottom layers | 4 top layers, 3 bottom layers
Infill | 20%
Infill pattern | Gyroid recommended, cubic also sufficient
Supports | Always on build plate only and add supports only where specified per
part. Standard threshold angle at 30◦
Build plate adhesion | Use a brim only where specified per part
Print orientation | Use the orientation shown per part
Printing speed | Use the standard speed settings from your dedicated printer, unless
stated otherwise
Units | Millimetres

Tolerances and Fit

Some parts may need light sanding, cleaning, or adjustment after printing. If parts are too tight, it is recommended to slightly reduce flow rate or increase horizontal expansion compensation in the slicer. Changing dimensions using CAD-software is also a possibility.
If parts are too loose, increase the wall count or check the printer calibration. Again, changing dimensions is a great alternative if only slicer setting changes are not sufficient.

OpenSource CDS | Printing Guide | 3

## Parts Overview

The following 3D printed parts are required for the full project.

Part | Quantity
BASE_base | 1
BASE_bridge | 1
BASE_electro | 1
BASE_electro_lid | 1
BASE_light_mount_base | 1
BASE_light_mount_swivel | 1
BASE_ruler | 1
BASE_top_cap | 1
BASE_switch_housing | 1
BLOCKS_camera_block | 1
BLOCKS_camera_cap | 1
BLOCKS_camera_nut_holder | 1
BLOCKS_cap | 2
BLOCKS_detector_block | 1
BLOCKS_detector_clamp | 1
BLOCKS_detector_q_slider | 1
BLOCKS_detector_side_slider | 1
BLOCKS_f1_block | 1
BLOCKS_f2_block | 1
BLOCKS_guide_spacer | 1
BLOCKS_laser_block | 1
BLOCKS_laser_cap | 1
BLOCKS_laser_spacer | 1
BLOCKS_lens_clamp | 2
BLOCKS_mirror_block | 2
BLOCKS_mirror_clamp_bottom | 2
BLOCKS_mirror_clamp_top | 1
BLOCKS_redfilter_clamp_top | 1
BLOCKS_spacer_0.4 | 1
BLOCKS_spacer_0.8 | 1
BLOCKS_spacer_1.2 | 1
BLOCKS_spacer_1.6 | 1
BLOCKS_spacer_2.0 | 1
BLOCKS_spacer_2.4 | 1
BLOCKS_spacer_2.8 | 1
BLOCKS_spacer_3.2 | 1
BLOCKS_spacer_box | 1

OpenSource CDS | Printing Guide | 4
Part | Quantity
CALIBRATION_spacer_0.2 | 1
CALIBRATION_spacer_0.4 | 1
CALIBRATION_spacer_0.6 | 1
CALIBRATION_spacer_0.8 | 1
CALIBRATION_spacer_1 | 1
CALIBRATION_spacer_2 | 1
CALIBRATION_spacer_3 | 1
CALIBRATION_spacer_4 | 1
CALIBRATION_spacer_5 | 1
CALIBRATION_spacer_6 | 1
CALIBRATION_spacer_7 | 1
CALIBRATION_spacer_8 | 1
CALIBRATION_spacer_box | 1
CALIBRATION_table_calibrator | 1
STAGE_actuator_tools | 1
STAGE_gear | 3
STAGE_main_base | 1
STAGE_main_body | 1
STAGE_moving_platform | 1
STAGE_small_gear | 3

OpenSource CDS | Printing Guide | 5

## BASE_base

Quantity | 1
Wall count | Preferably 3
Supports | On highlighted faces only - Style: normal
Speed | Standard
Notes | -

## BASE_bridge

Quantity | 1
Wall count | 2
Supports | -
Speed | Standard
Notes | -

## BASE_electro

Quantity | 1
Wall count | 2
Supports | On highlighted faces only - Style: normal
Speed | Standard
Notes | -

OpenSource CDS | Printing Guide | 6

## BASE_electro_lid

Quantity | 1
Wall count | 2
Supports | -
Speed | Standard
Notes | -

## BASE_light_mount_base

Quantity | 1
Wall count | 2
Supports | -
Speed | Standard
Notes | -

## BASE_light_mount_swivel

Quantity | 1
Wall count | 2
Supports | -
Speed | Standard
Notes | -

OpenSource CDS | Printing Guide | 7

## BASE_ruler

Quantity | 1
Wall count | 2
Supports | On highlighted faces only - Style: normal
Speed | Standard
Notes | -

## BASE_top_cap

Quantity | 1
Wall count | 2
Supports | -
Speed | Standard
Notes | -

## BASE_switch_housing

Quantity | 1
Wall count | 2
Supports | -
Speed | Standard
Notes | -

OpenSource CDS | Printing Guide | 8

## BLOCKS_camera_block

Quantity | 1
Wall count | 2
Supports | On highlighted faces only - Style: tree
Speed | Standard
Notes | -

## BLOCKS_camera_cap

Quantity | 1
Wall count | 2
Supports | -
Speed | Standard
Notes | -

## BLOCKS_camera_nut_holder

Quantity | 1
Wall count | 2
Supports | -
Speed | Standard
Notes | -

OpenSource CDS | Printing Guide | 9

## BLOCKS_cap

Quantity | 2
Wall count | 2
Supports | -
Speed | Standard
Notes | -

## BLOCKS_detector_block

Quantity | 1
Wall count | 2
Supports | On highlighted faces only - Style: normal
Speed | Standard
Notes | -

## BLOCKS_detector_clamp

Quantity | 1
Wall count | 2
Supports | -
Speed | Standard
Notes | -

OpenSource CDS | Printing Guide | 10

## BLOCKS_detector_q_slider

Quantity | 1
Wall count | 2
Supports | -
Speed | Standard
Notes | -

## BLOCKS_detector_side_slider

Quantity | 1
Wall count | 2
Supports | On highlighted faces only - Style: tree
Speed | Standard
Notes | -

## BLOCKS_f1_block

Quantity | 1
Wall count | 2
Supports | -
Speed | Standard
Notes | -

OpenSource CDS | Printing Guide | 11

## BLOCKS_f2_block

Quantity | 1
Wall count | 2
Supports | On highlighted faces only - Style: normal
Speed | Standard
Notes | -

## BLOCKS_guide_spacer

Quantity | 1
Wall count | 2
Supports | On highlighted faces only - Style: normal
Speed | Standard
Notes | -

## BLOCKS_laser_block

Quantity | 1
Wall count | 2
Supports | On highlighted faces only - Style: tree
Speed | Standard
Notes | -

OpenSource CDS | Printing Guide | 12

## BLOCKS_laser_cap

Quantity | 1
Wall count | 2
Supports | -
Speed | Standard
Notes | -

## BLOCKS_laser_spacer

Quantity | 1
Wall count | 2
Supports | -
Speed | Standard
Notes | -

## BLOCKS_lens_clamp

Quantity | 2
Wall count | 2
Supports | -
Speed | Standard
Notes | -

OpenSource CDS | Printing Guide | 13

## BLOCKS_mirror_block

Quantity | 2
Wall count | 2
Supports | On highlighted faces only - Style: tree
Speed | Standard
Notes | -

## BLOCKS_mirror_clamp_bottom

Quantity | 2
Wall count | 2
Supports | On highlighted faces only - Style: normal
Speed | Standard
Notes | -

## BLOCKS_mirror_clamp_top

Quantity | 1
Wall count | 2
Supports | -
Speed | Standard
Notes | -

OpenSource CDS | Printing Guide | 14

## BLOCKS_redfilter_clamp_top

Quantity | 1
Wall count | 2
Supports | -
Speed | Standard
Notes | -

## BLOCKS_spacers

Quantity | 8
Wall count | 2
Supports | -
Speed | Standard
Notes | Print all individual spacers (from 0.4 to 3.2mm) with the same settings

## BLOCKS_spacer_box

Quantity | 1
Wall count | 2
Supports | -
Speed | Standard
Notes | -

OpenSource CDS | Printing Guide | 15

## CALIBRATION_spacers

Quantity | 12
Wall count | 2
Supports | -
Speed | Standard
Notes | Print all individual spacers (from 0.2 to 8mm) with the same settings

## CALIBRATION_spacer_box

Quantity | 1
Wall count | 2
Supports | -
Speed | Standard
Notes | -

## CALIBRATION_table_calibrator

Quantity | 1
Wall count | 2
Supports | -
Speed | Standard
Notes | -

OpenSource CDS | Printing Guide | 16

## STAGE_actuator_tools

Quantity | 1 needed, preferably 3 (they break easily)
Wall count | 2
Supports | -
Speed | Walls: 40mm/s Infill: 80mm/s Bridges: 30mm/s
Notes | Printing settings copied from the OpenFlexure Block Stage assembly instructions

## STAGE_gear

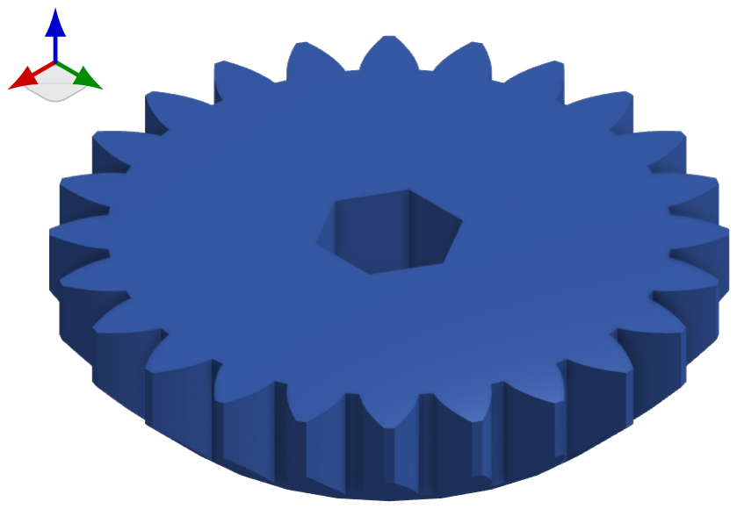
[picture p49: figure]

Quantity | 3
Wall count | 2
Supports | -
Speed | Walls: 40mm/s Infill: 80mm/s Bridges: 30mm/s
Notes | Printing settings copied from the OpenFlexure Block Stage assembly instructions

## STAGE_main_base

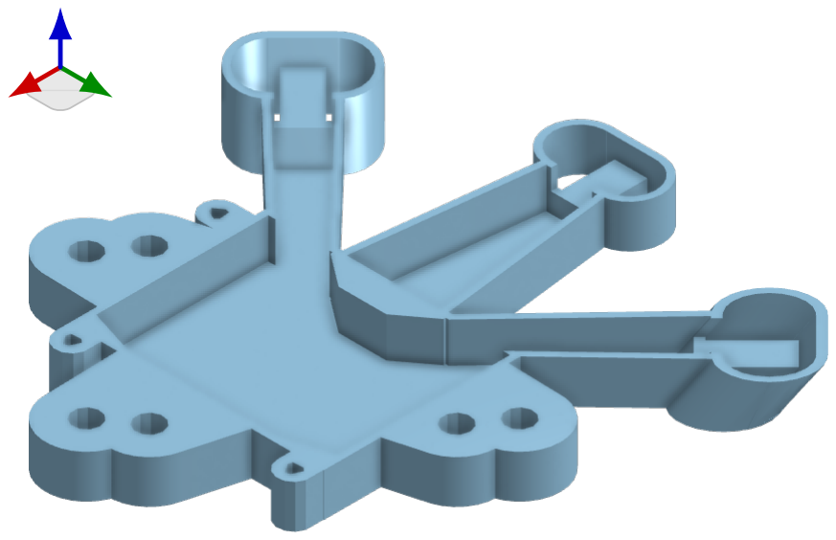
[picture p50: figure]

Quantity | 1
Wall count | 2
Supports | -
Speed | Walls: 40mm/s Infill: 80mm/s Bridges: 30mm/s
Notes | Printing settings copied from the OpenFlexure Block Stage assembly instructions

OpenSource CDS | Printing Guide | 17

## STAGE_main_body

Quantity | 1
Wall count | 2
Supports | -
Speed | Walls: 40mm/s Infill: 80mm/s Bridges: 30mm/s
Notes | Printing settings copied from the OpenFlexure Block Stage assembly instructions

## STAGE_moving_platform

Quantity | 1
Wall count | 2
Supports | -
Speed | Walls: 40mm/s Infill: 80mm/s Bridges: 30mm/s
Notes | Printing settings copied from the OpenFlexure Block Stage assembly instructions

## STAGE_small_gear

Quantity | 3
Wall count | 2
Supports | -
Speed | Walls: 40mm/s Infill: 80mm/s Bridges: 30mm/s
Notes | Printing settings copied from the OpenFlexure Block Stage assembly instructions

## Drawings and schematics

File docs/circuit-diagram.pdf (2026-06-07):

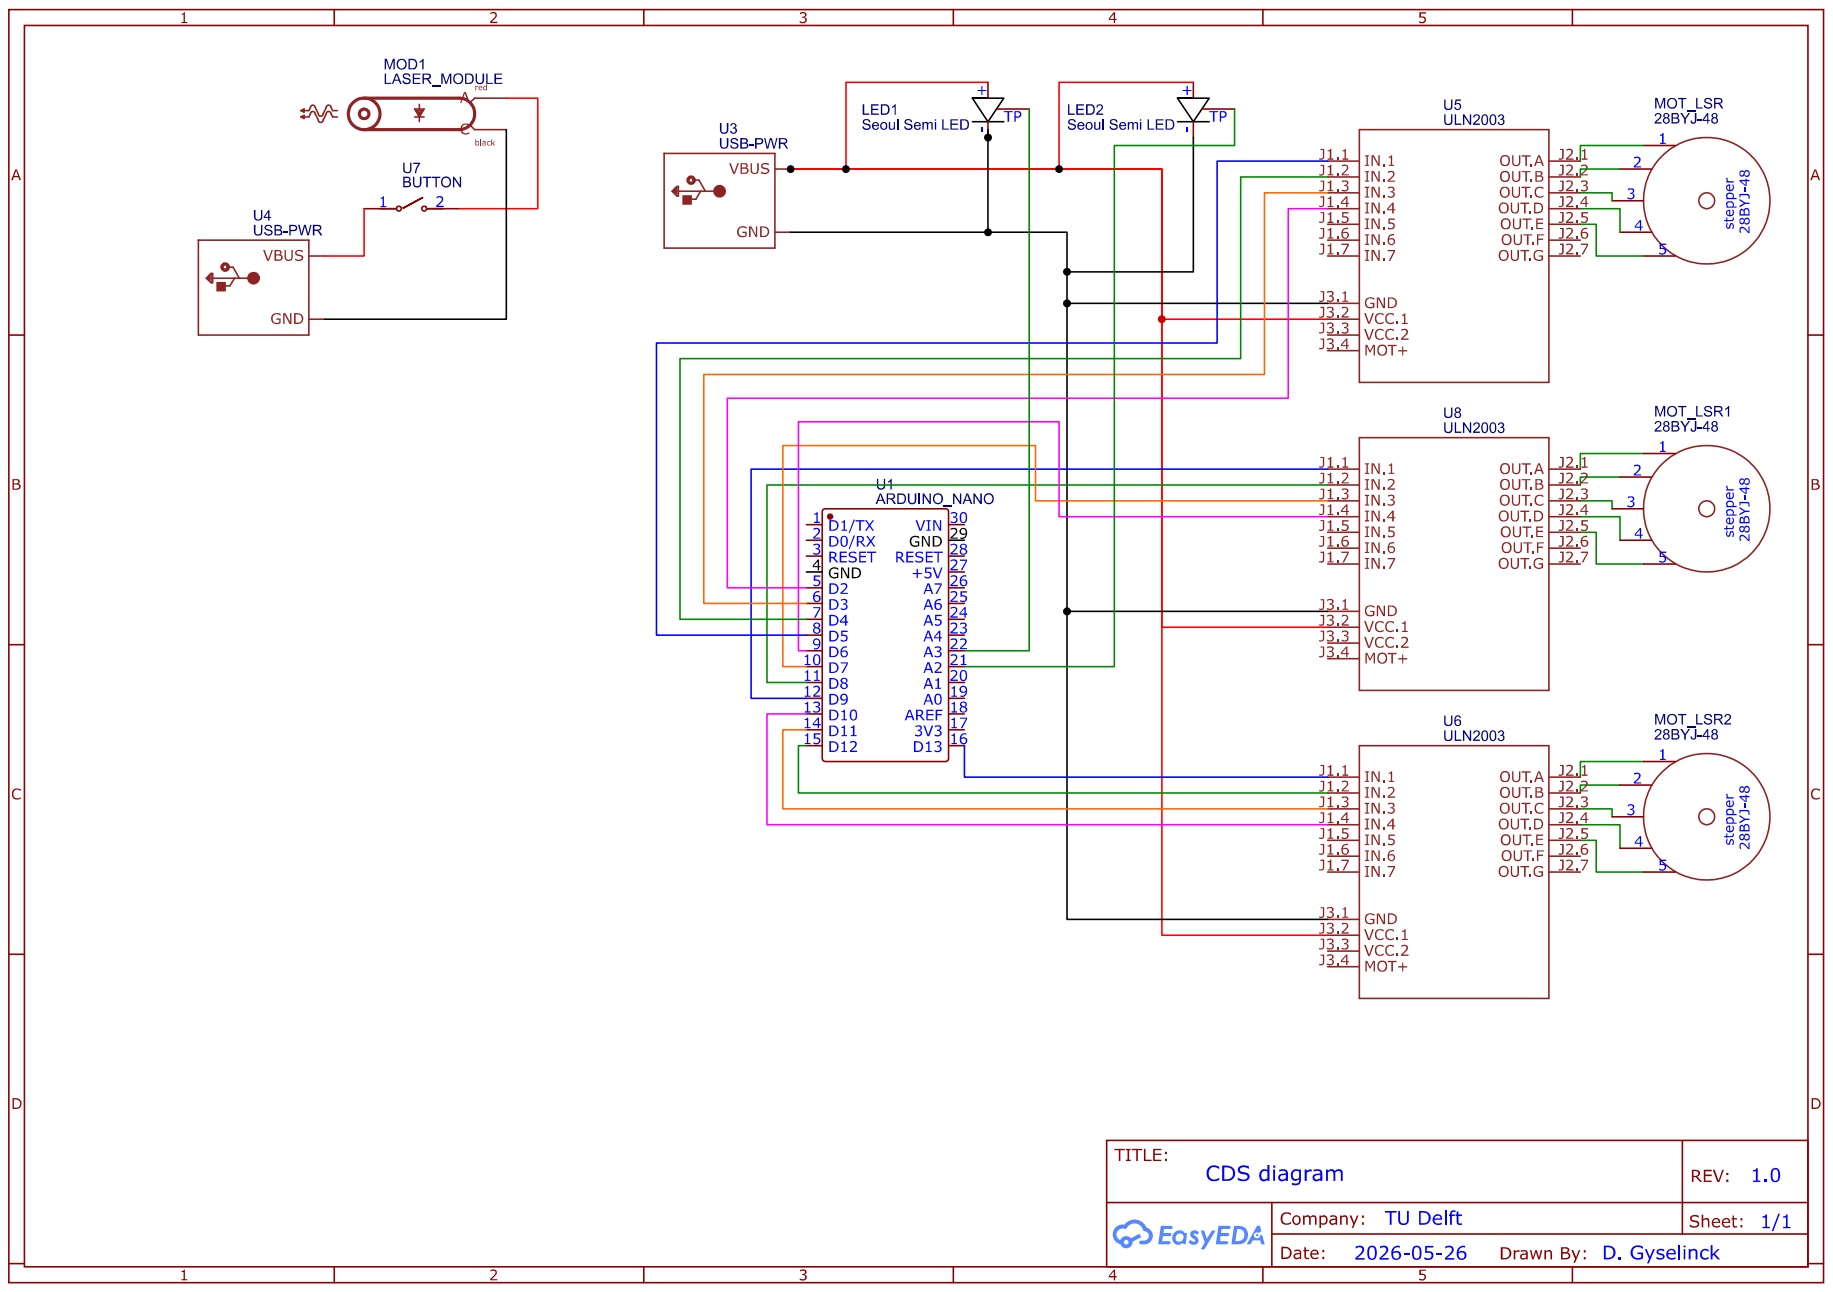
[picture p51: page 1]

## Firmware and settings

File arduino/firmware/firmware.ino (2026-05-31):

// SPDX-License-Identifier: MIT
// Bep-Project firmware voor Arduino Nano
// Hardware: 3x 28BYJ-48 + ULN2003 + WS2812B-8 (NeoPixel)
//
// Ontvangt ASCII-commando's over USB-serial @ 9600 baud:
//   "1 500\n"          -> motor 1 naar absolute positie 500 stappen
//   "2 -250\n"         -> motor 2 naar -250
//   "3 1000\n"         -> motor 3 naar 1000
//   "SPEED 600\n"      -> max snelheid voor alle motoren (stappen/s)
//   "STOP\n"           -> noodstop, alle motoren onmiddellijk stil
//   "LAMP 128\n"       -> WS2812B-helderheid lamp BINNEN 0..255 (alle 8 pixels wit)
//   "LAMP2 128\n"      -> WS2812B-helderheid lamp BUITEN 0..255 (alle 8 pixels wit)
//   "SETPOS 1 0\n"     -> zet motor 1 op positie 0 zonder te bewegen (soft-home)
//   "WHERE\n"          -> antwoord: "POS <m1> <m2> <m3>"  (huidige posities)
//   "BUSY?\n"          -> antwoord: "BUSY 1" (rijdt) of "BUSY 0" (stilstand)
//   "GOTO 100 -50 0\n" -> alle 3 motoren tegelijk naar absolute target
//
// Hardware-aannames:
//   - 3x ULN2003 driverbord met 28BYJ-48 motor:
//       Motor 1 ULN2003: IN1=D2, IN2=D3, IN3=D4, IN4=D5
//       Motor 2 ULN2003: IN1=D6, IN2=D7, IN3=D8, IN4=D9
//       Motor 3 ULN2003: IN1=D10, IN2=D11, IN3=D12, IN4=D13  (D13 = onboard LED, flickert mee)
//     ULN2003-boards: VCC = aparte 5V voeding, GND = gemeenschappelijk met Arduino GND
//   - WS2812B-8 ring BINNEN: DIN op A2 (= digital pin 16), via 470 ohm
//   - WS2812B-8 ring BUITEN: DIN op A3 (= digital pin 17), via 470 ohm
//
// AccelStepper FULL4WIRE pin-volgorde-truc:
//   28BYJ-48 + ULN2003 wordt fysiek bedraad als IN1-IN2-IN3-IN4,
//   maar het step-sequence patroon is IN1-IN3-IN2-IN4.
//   Daarom swappen we pin 2 en pin 3 in de constructor.
//
// Library: Adafruit NeoPixel + AccelStepper (beide via Library Manager)

#include <AccelStepper.h>
#include <Adafruit_NeoPixel.h>

// ---- Motor pin-config (FULL4WIRE, volgorde IN1, IN3, IN2, IN4) -
AccelStepper m1(AccelStepper::FULL4WIRE, 2,  4,  3,  5);
AccelStepper m2(AccelStepper::FULL4WIRE, 6,  8,  7,  9);
AccelStepper m3(AccelStepper::FULL4WIRE, 10, 12, 11, 13);

// ---- Lamp config -----------------------------------------------
const uint8_t LAMP_PIN    = 16;   // A2 = D16 op de Nano (lamp BINNEN)
const uint8_t LAMP2_PIN   = 17;   // A3 = D17 op de Nano (lamp BUITEN)
const uint8_t LAMP_COUNT  = 8;

Adafruit_NeoPixel lamp (LAMP_COUNT, LAMP_PIN,  NEO_GRB + NEO_KHZ800);  // binnen
Adafruit_NeoPixel lampB(LAMP_COUNT, LAMP2_PIN, NEO_GRB + NEO_KHZ800);  // buiten

// ---- Globals ---------------------------------------------------
float currentMaxSpeed = 500.0f;
String inbuf;

void applySpeed(float v) {
  currentMaxSpeed = v;
  m1.setMaxSpeed(v); m1.setAcceleration(v * 4);
  m2.setMaxSpeed(v); m2.setAcceleration(v * 4);
  m3.setMaxSpeed(v); m3.setAcceleration(v * 4);
}

void emergencyStop() {
  m1.stop(); m2.stop(); m3.stop();
  m1.setCurrentPosition(m1.currentPosition());
  m2.setCurrentPosition(m2.currentPosition());
  m3.setCurrentPosition(m3.currentPosition());
}

void setLamp(uint8_t brightness) {
  lamp.setBrightness(brightness);
  for (uint8_t i = 0; i < LAMP_COUNT; i++) {
    lamp.setPixelColor(i, lamp.Color(255, 255, 255));
  }
  lamp.show();
}

void setLampB(uint8_t brightness) {
  lampB.setBrightness(brightness);
  for (uint8_t i = 0; i < LAMP_COUNT; i++) {
    lampB.setPixelColor(i, lampB.Color(255, 255, 255));
  }
  lampB.show();
}

void handleCommand(const String& line) {
  if (line.length() == 0) return;

  if (line == "STOP") {
    emergencyStop();
    Serial.println("OK STOP");
    return;
  }
  if (line.startsWith("SPEED ")) {
    float v = line.substring(6).toFloat();
    if (v > 0) {
      applySpeed(v);
      Serial.print("OK SPEED "); Serial.println(v);
    }
    return;
  }
  if (line.startsWith("LAMP2 ")) {
    int b = line.substring(6).toInt();
    b = constrain(b, 0, 255);
    setLampB((uint8_t)b);
    Serial.print("OK LAMP2 "); Serial.println(b);
    return;
  }
  if (line.startsWith("LAMP ")) {
    int b = line.substring(5).toInt();
    b = constrain(b, 0, 255);
    setLamp((uint8_t)b);
    Serial.print("OK LAMP "); Serial.println(b);
    return;
  }
  if (line == "WHERE") {
    Serial.print("POS ");
    Serial.print(m1.currentPosition()); Serial.print(' ');
    Serial.print(m2.currentPosition()); Serial.print(' ');
    Serial.println(m3.currentPosition());
    return;
  }
  if (line == "BUSY?") {
    bool busy = (m1.distanceToGo() != 0)
             || (m2.distanceToGo() != 0)
             || (m3.distanceToGo() != 0);
    Serial.print("BUSY "); Serial.println(busy ? 1 : 0);
    return;
  }
  if (line.startsWith("GOTO ")) {
    // GOTO <m1> <m2> <m3>
    int sp1 = line.indexOf(' ', 5);
    if (sp1 <= 0) return;
    int sp2 = line.indexOf(' ', sp1 + 1);
    if (sp2 <= 0) return;
    long t1 = line.substring(5, sp1).toInt();
    long t2 = line.substring(sp1 + 1, sp2).toInt();
    long t3 = line.substring(sp2 + 1).toInt();
    m1.moveTo(t1);
    m2.moveTo(t2);
    m3.moveTo(t3);
    Serial.print("OK GOTO "); Serial.print(t1);
    Serial.print(' '); Serial.print(t2);
    Serial.print(' '); Serial.println(t3);
    return;
  }
  if (line.startsWith("SETPOS ")) {
    // SETPOS <motor> <position>
    int sp = line.indexOf(' ', 7);
    if (sp <= 0) return;
    int motor = line.substring(7, sp).toInt();
    long pos = line.substring(sp + 1).toInt();
    AccelStepper* m = nullptr;
    switch (motor) {
      case 1: m = &m1; break;
      case 2: m = &m2; break;
      case 3: m = &m3; break;
      default: return;
    }
    m->setCurrentPosition(pos);
    Serial.print("OK SETPOS "); Serial.print(motor);
    Serial.print(' '); Serial.println(pos);
    return;
  }
  // Anders: "<motor> <target>"
  int sp = line.indexOf(' ');
  if (sp <= 0) return;
  int motor = line.substring(0, sp).toInt();
  long target = line.substring(sp + 1).toInt();
  switch (motor) {
    case 1: m1.moveTo(target); break;
    case 2: m2.moveTo(target); break;
    case 3: m3.moveTo(target); break;
    default: return;
  }
  Serial.print("OK "); Serial.print(motor);
  Serial.print(" "); Serial.println(target);
}

void setup() {
  Serial.begin(9600);

  applySpeed(currentMaxSpeed);

  lamp.begin();
  lamp.setBrightness(0);
  lamp.show();

  lampB.begin();
  lampB.setBrightness(0);
  lampB.show();

  inbuf.reserve(32);
  Serial.println("READY");
}

void loop() {
  while (Serial.available()) {
    char c = (char)Serial.read();
    if (c == '\n' || c == '\r') {
      if (inbuf.length() > 0) {
        handleCommand(inbuf);
        inbuf = "";
      }
    } else if (inbuf.length() < 64) {
      inbuf += c;
    }
  }
  m1.run();
  m2.run();
  m3.run();
}

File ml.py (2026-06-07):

# SPDX-License-Identifier: MIT

"""Confocaal sensor-model (A6): fit van q en r0 op meetpunten.

Kern: `fit_confocal(dz1, Im, f1, ...)` fit q en r0 (gradient descent) op
gemeten (dz1, I_m)-punten en geeft een FitResult terug. Géén plot, géén
bestand-IO — zo is de fit herbruikbaar vanuit de UI (calibration_graph.py)
en vanuit het __main__-blok onderaan.

  * input  : dz1 = verplaatsing (mm), I_m = gemeten intensiteit (V)
  * geleerd : q, r0
  * vast    : f1, f2, L, r_d ; I0 = max(meting)

Het A6-model en de symbolische gradients staan op module-niveau (één keer
gelambdify'd), zodat herhaald fitten goedkoop is.
"""
from __future__ import annotations

from dataclasses import dataclass

import numpy as np
import sympy as sp


# --- Vaste default-parameters (mm), spiegelt confocal.py ---
F2_DEFAULT = 150.0
L_DEFAULT = 66.0
RD_DEFAULT = 0.5

# --- Theoretische parameters (confocal.py), voor de overlay-vergelijking ---
q_theory = 32.75    # mm
r0_theory = 2.75    # mm


# --- Symbolisch FORWARD model A6: I_m(dz1) (zie confocal.py regels 36-39) ---
_dz1, _q, _r0, _f1, _f2, _L, _rd, _I0 = sp.symbols(
    "dz1 q r0 f1 f2 L rd I0", real=True
)
_rdet = _r0 / (_f1**2 * _f2) * (
    2 * _dz1 * (_q * (_f1 + _f2 - _L) + _f2**2) - _q * _f1**2
)
_Im = _I0 - _I0 * sp.exp(-_rd**2 / _rdet**2)

_args = (_dz1, _q, _r0, _f1, _f2, _L, _rd, _I0)
Im_func = sp.lambdify(_args, _Im, "numpy")
dIm_dq = sp.lambdify(_args, sp.diff(_Im, _q), "numpy")
dIm_dr0 = sp.lambdify(_args, sp.diff(_Im, _r0), "numpy")


@dataclass
class FitResult:
    """Resultaat van fit_confocal — geleerde parameters + fit-kwaliteit."""
    q: float
    r0: float
    I0: float
    R2: float
    RMSE: float
    f1: float
    f2: float
    L: float
    r_d: float


@dataclass
class LinearizationResult:
    """Resultaat van linearize_midpoint — rechte a*x + b rond I0/2.

    a = helling (V/mm), b = intercept (V). lo/hi begrenzen de spanningsband
    waarbinnen de meetpunten zijn meegenomen; n = aantal gebruikte punten;
    x_lo/x_hi = dz1-bereik van die punten (handig om de lijn te tekenen).
    """
    a: float
    b: float
    I0: float
    lo: float
    hi: float
    n: int
    R2: float
    x_lo: float
    x_hi: float


def fit_confocal(
    dz1, Im, f1,
    f2: float = F2_DEFAULT, L: float = L_DEFAULT, r_d: float = RD_DEFAULT,
    q0: float = q_theory, r0_0: float = 1.0,
    epochs: int = 20000, lr_q: float = 1.0, lr_r0: float = 1e-3,
) -> FitResult:
    """Fit q en r0 op (dz1, Im)-punten via gradient descent. I0 = max(Im).

    q heeft een veel kleinere gradient dan r0 (zit diep in de noemer van
    r_det), dus q krijgt een eigen, grotere learning rate (lr_q), anders kruipt
    hij. r0 mag niet 0 zijn (staat in de noemer van r_det).
    """
    dz1 = np.asarray(dz1, dtype=np.float64)
    Im = np.asarray(Im, dtype=np.float64)
    n = dz1.size
    if n < 2:
        raise ValueError("At least 2 data points needed for a fit.")

    I0 = float(Im.max())
    q = float(q0)
    r0 = float(r0_0)

    for _ in range(epochs):
        with np.errstate(divide="ignore", invalid="ignore"):
            y_pred = Im_func(dz1, q, r0, f1, f2, L, r_d, I0)
            grad_q = dIm_dq(dz1, q, r0, f1, f2, L, r_d, I0)
            grad_r0 = dIm_dr0(dz1, q, r0, f1, f2, L, r_d, I0)
        error = y_pred - Im
        q -= lr_q * (2 / n) * np.dot(error, grad_q)
        r0 -= lr_r0 * (2 / n) * np.dot(error, grad_r0)

    with np.errstate(divide="ignore", invalid="ignore"):
        y_pred = Im_func(dz1, q, r0, f1, f2, L, r_d, I0)
    error = y_pred - Im
    ss_tot = float(np.sum((Im - np.mean(Im)) ** 2))
    R2 = float(1 - np.sum(error**2) / ss_tot) if ss_tot > 0 else float("nan")
    RMSE = float(np.sqrt(np.mean(error**2)))

    return FitResult(
        q=float(q), r0=float(r0), I0=I0, R2=R2, RMSE=RMSE,
        f1=float(f1), f2=float(f2), L=float(L), r_d=float(r_d),
    )


def linearize_midpoint(
    dz1, Im, lo_frac: float = 0.2, hi_frac: float = 0.4, side: str = "left",
) -> LinearizationResult:
    """Lineariseer (a*x + b) het steile midden van de confocale curve rond I0/2.

    Selecteert enkel de meetpunten waarvan de spanning binnen de band
    [I0/2 - lo_frac*I0, I0/2 + hi_frac*I0] valt (I0 = max van de meting) en fit
    daarop een rechte met kleinste-kwadraten (np.polyfit). Punten buiten de band
    tellen niet mee. Geeft a (V/mm), b (V) en de bandgrenzen terug.

    De confocale curve heeft twee flanken; dezelfde spanning komt links en rechts
    van de piek voor. `side` kiest welke flank wordt gefit ("left" = links van de
    top, "right" = rechts, "both" = beide). De top is het punt met max spanning.
    """
    dz1 = np.asarray(dz1, dtype=np.float64)
    Im = np.asarray(Im, dtype=np.float64)

    I0 = float(Im.max())
    lo = I0 / 2 - lo_frac * I0
    hi = I0 / 2 + hi_frac * I0
    mask = (Im >= lo) & (Im <= hi)

    # Beperk tot één flank: de top ligt bij dz1 van het maximum.
    dz1_peak = float(dz1[int(np.argmax(Im))])
    if side == "left":
        mask &= dz1 <= dz1_peak
    elif side == "right":
        mask &= dz1 >= dz1_peak
    elif side != "both":
        raise ValueError(f"Unknown side: {side!r} (expected left/right/both).")

    if int(mask.sum()) < 2:
        raise ValueError(
            "Too few points within the band for linearization "
            f"(found {int(mask.sum())}, at least 2 needed)."
        )

    x_in, y_in = dz1[mask], Im[mask]
    a, b = np.polyfit(x_in, y_in, 1)

    y_pred = a * x_in + b
    ss_res = float(np.sum((y_in - y_pred) ** 2))
    ss_tot = float(np.sum((y_in - y_in.mean()) ** 2))
    R2 = float(1 - ss_res / ss_tot) if ss_tot > 0 else float("nan")

    return LinearizationResult(
        a=float(a), b=float(b), I0=I0, lo=lo, hi=hi,
        n=int(mask.sum()), R2=R2,
        x_lo=float(x_in.min()), x_hi=float(x_in.max()),
    )
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

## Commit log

2026-04-20 V1 opzet
    [sweep_output.csv]
2026-04-21 updates aan code
    [sweep_output.csv]
2026-04-22 base functions in confocal
    [paper_table_1mm.csv, paper_table_1um.csv, sweep_output.csv]
2026-04-22 range change x-axis
2026-04-23 camera en moku(opzet)
    de moku:go code werkt nog niet
2026-04-28 lenzen + readme
    [gridsearch_results.csv]
2026-05-04 calibratie, meet automatisering v1
    [calibration.yaml, gridsearch_results.csv, measurement.csv]
2026-05-04 ui updates
    [calibration.yaml]
2026-05-04 code base opgeruimd
    [calibration.yaml, gridsearch_results.csv, measurement.csv]
2026-05-13 Lamp ui Camera settings
2026-05-19 camera, datalogger, ui
2026-05-21 Repo cleanup: remove unused scripts, update README and requirements
    - Remove camera.py, moku_live.py (unused standalones, functionality embedded in UI)
    - Remove exploded_view.py (Blender test script)
    - Remove docs/ (RUN_GUIDE.md + setup_sketch.jpg)
    - Rewrite README.md to reflect current burst-mode pipeline and actual file structure
    - Drop scipy and pytest from requirements.txt (no longer used)
    - Clean up ui.py docstring references to deleted files
    [ui.py]
2026-05-31 fix: block stage gebruikt unmodified (geen derivative); license-formulering aangepast
2026-05-31 docs: bom.xlsx + print-guide.pdf live; skeletons weg, hub-tabel + status bijgewerkt
    [bom.xlsx]
2026-05-31 cad: 38 STEP files (BASE/BLOCKS/CALIBRATION) + cad/README.md, hub bijgewerkt
    [BASE_base.step, BASE_bridge.step, BASE_electro.step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]
2026-05-31 fix: dode link naar docs/bom.md (was hernoemd naar .xlsx)
2026-06-02 machine learning
    [metingen.xlsx]
2026-06-08 extra functies omtrent calibration
2026-06-08 readme updates
    [OpenSource_CDS_BOM.xlsx, bom.xlsx]
2026-06-09 gitignore updates
    [Metingen 25 mm.xlsx, Metingen 60 mm.xlsx, metingen 16 mm.xlsx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]
2026-06-09 Fix image syntax in README for better rendering
    Updated image syntax for the CAD render of the sensor.
2026-06-09 cad file updates
    [CALIBRATION_spacer_0.2.step, CALIBRATION_spacer_0.4.step, CALIBRATION_spacer_0.6.step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]
2026-06-11 spectrum data
    [snelheid 200.csv, snelheid 250.csv, snelheid 300.csv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]
2026-06-11 Update YouTube link for assembly video
